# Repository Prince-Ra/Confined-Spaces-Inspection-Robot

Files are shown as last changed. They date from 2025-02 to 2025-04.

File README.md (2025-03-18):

# **Development of a Mobile Robot for Autonomous & Manual Inspection of Confined Spaces Using Multi-Sensor Detection Systems**  

This repository contains the code, simulations, and documentation for my final-year internship project. The project focuses on designing and developing an autonomous mobile robot equipped with a **multi-sensor detection system** for navigating and inspecting confined spaces. The system supports both **autonomous** and **manual navigation**, making it adaptable to various inspection scenarios.  

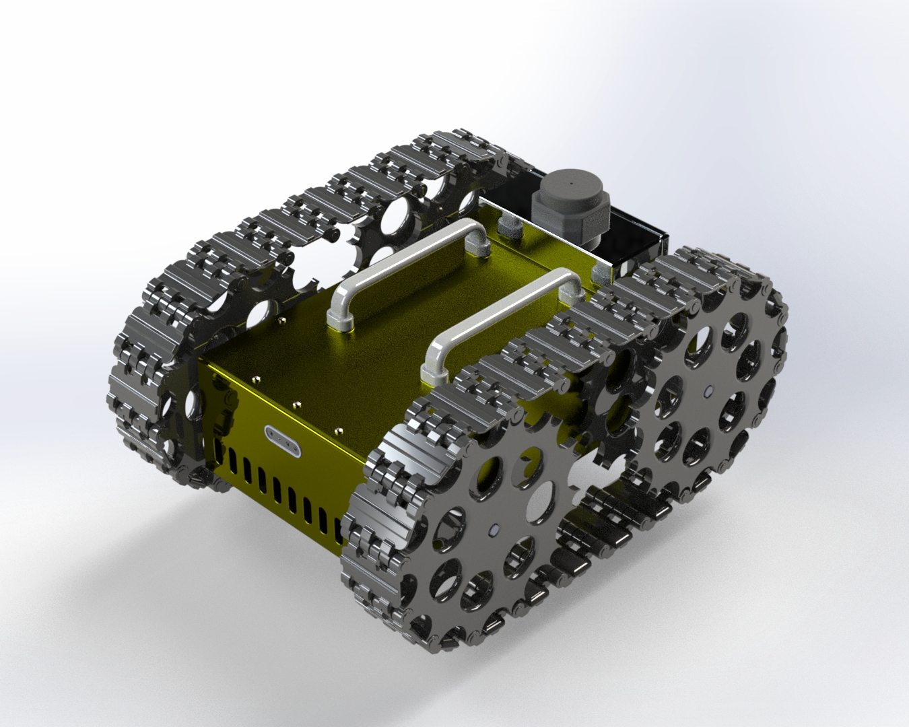
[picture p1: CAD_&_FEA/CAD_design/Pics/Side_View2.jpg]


## **Project Overview**  
🚀 **Autonomous & Manual Navigation**: Supports **autonomous path planning** and **manual control via RF remote interface**.  
🔍 **Multi-Sensor**: Integrated **LiDAR, stereo cameras, IMU, motor encoders, gas sensors, and temperature & humidity sensors** for comprehensive environmental monitoring.

🛠 **PCB Modular Sensor Hub**: Designed to adapt to multiple **sensors**.  
🎯 **Embedded Systems Development**: Developed firmware for **Jetson and STM32**.  
📊 **Structural & Thermal Analysis**: Conducted **FEA for vibration and load assessment** and **CFD for electronics cooling optimization** using **ANSYS**.  

## **Features**  
- **Autonomous Navigation**: ROS-based path planning and obstacle avoidance.  
- **Manual Navigation**: Remote control via a radiomaster.  
- **Multi-Sensor**:  
  - **LiDAR & Stereo Cameras** → Mapping & Obstacle Detection  
  - **IMU & Encoders** → Precise Localization  
  - **Gas, Temperature & Humidity Sensors** → Environmental Monitoring  
- **Gazebo-Based Simulation**: Virtual environment for testing and validation.  
- **ROS Integration**: Efficient robot control, mapping, and localization.  
- **PCB Modular Sensor Hub**: Compatible with different sensors for flexibility.  
- **Embedded Control**: Jetson for processing & STM32 for sensor acquisition and motor control.  
- **Structural & Thermal Optimization**: Vibration & Load Analysis ,Thermal Management for Electronics 

## **Contents**  
📂 **Code**: Navigation algorithms, sensor fusion logic, embedded firmware, and ROS nodes.  
📄 **Documentation**: System architecture, hardware design, sensor integration, and experimental results.  
🏗 **Simulations**: Gazebo environments for real-world scenario validation.  

## **Technologies Used**  
- **Programming Languages**: Python , C/C++  
- **Frameworks & Tools**: ROS2, OpenCV
- **Computer Aided design**: Solidworks
- **Simulation & Analysis**: Gazebo , ANSYS 
- **Hardware**: **LiDAR, stereo cameras, IMU, motor encoders, gas sensors, temperature & humidity sensors, Jetson, STM32**  

## **Contributing**  
Contributions are welcome! Feel free to submit issues, feature requests, or pull requests.  

## **Contact**  
For inquiries or collaboration, reach out via moataz.seghyar@usmba.ac.ma or connect on my linkedin page at Moataz Seghyar.

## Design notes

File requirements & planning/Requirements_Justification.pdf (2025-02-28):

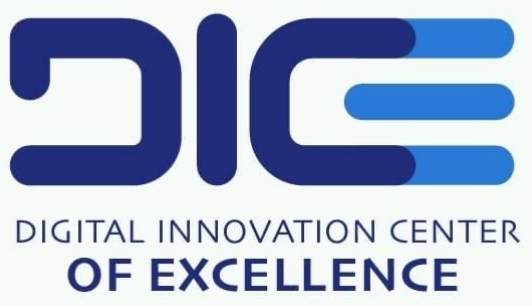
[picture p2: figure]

# Inspection Robot for Confined Spaces

## Requirements Justification

## Moataz SEGHYAR

### Document Purpose

This document is complementary to the specification document, providing detailed justifications for the selection of the various components used in the Inspection Robot for Confined Spaces. While the specification document outlines the technical requirements and design parameters, this document focuses on the analytical and engineering rationale behind the chosen components, ensuring that the design meets the operational requirements effectively and efficiently.

## Contents

1 Justification of Dimensions | 2
2 Justification of the Simplified Track System and Worm Drive Mechanism | 3
3 Fabrication Method Selection | 4
4 Material Selection Justification | 5
5 Motor Selection Justification | 8
6 Battery Selection Justification | 11
7 Power Consumption Analysis | 11

## Introduction

The proposed tracked robotic system is designed for navigation in confined and challenging environments, integrating Lidar, cameras, and multiple sensors for autonomous operation. Given its mission-critical requirements, the different parts have been carefully selected to balance mobility, stability, and payload capacity. This report provides a formal justification for maintaining these dimensions while optimizing weight, power consumption, and maneuverability.

## 1 Justification of Dimensions

The dimensions of 40x50x30 cm were chosen to ensure stability, traction, and maneuverability in confined and uneven environments. Key considerations include:

- Height (30 cm): Ensures operation within confined spaces (maximum height: 60 cm), providing clearance for sensors and mechanical extensions while maintaining flexibility.
- Low Center of Gravity: The 30 cm height reduces tipping risks on slopes, rough terrain, or obstacles, enhancing stability during dynamic movements.
- Footprint (40x50 cm): A larger contact surface improves traction by distributing weight evenly across the tracks, preventing sinking in soft or uneven surfaces.
- Track Proportion: A balanced 50 cm length and 40 cm width optimize weight distribution, maximizing grip while minimizing turning resistance for better maneuverability.
- Load Distribution: The wider frame reduces pressure on individual track sections, minimizing wear and improving obstacle handling, especially with modular 3D-printed tracks.

These dimensions balance stability, traction, and maneuverability, ensuring effective operation in confined spaces without compromising structural integrity or mobility.

## 2 Justification of the Simplified Track System and Worm Drive Mechanism

The choice of the propulsion system is a critical factor in ensuring the robot’s effectiveness in confined environments. Instead of a traditional tank-like track system with multiple road wheels, a simplified track system with two primary drive wheels was selected. Additionally, a worm drive mechanism was implemented to optimize torque transmission. The rationale behind these choices is outlined below.

### 2.1 Simplified Track System

The simplified track system, driven by two large wheels, offers several advantages over traditional tank-like mechanisms:

- Reduced Complexity and Friction: Eliminates multiple contact points, reducing mechanical complexity and friction losses for improved energy efficiency.
- Compatibility with Modular 3D-Printed Tracks: Ensures uniform track engagement and reduces mechanical stress on 3D-printed components, avoiding misalignment issues.
- Efficient Torque Transfer: Directs motor torque through two main drive wheels, ensuring effective power delivery.
- Enhanced Maneuverability: Reduces unnecessary contact points, enabling smoother turns and better adaptability in tight spaces.

### 2.2 Worm Drive Mechanism

The worm drive mechanism provides critical benefits for the robot’s operation:

- High Torque and Low-Speed Output: Offers significant gear reduction, increasing torque while reducing speed—ideal for controlled movement.
- Self-Locking Capability: Prevents back-driving, enhancing stability on inclined surfaces when motors are inactive.
- Compact and Robust Design: Simplifies the drivetrain by eliminating the need for multi-stage gear reductions, making it suitable for confined spaces.

## 3 Fabrication Method Selection

### 3.1 Sheet Metal Design for Chassis

The chassis is fabricated using sheet metal design due to its superior strength-to-weight ratio, cost-effectiveness, and ease of forming. This method is particularly well-suited for creating large, flat components like the chassis, ensuring precise and durable structures. Sheet metal fabrication allows for efficient production through processes such as metal cold forming and metal press forming, which are ideal for achieving the required structural integrity and lightweight design necessary for confined-space navigation. Compared to alternatives like casting or 3D printing, sheet metal offers better scalability and faster production for large parts.

### 3.2 3D Printing for Wheels and Tracks

For the wheels and tracks, 3D printing is employed to leverage its ability to produce complex geometries and lightweight structures. This method is particularly advantageous for creating intricate designs that require flexibility and durability, such as modular tracks and custom wheel shapes. Unlike traditional manufacturing, 3D printing allows for rapid prototyping and customization, making it ideal for small, complex components. The process also reduces material waste and enables the use of high-strength polymers or composites, which are essential for optimizing the performance of the wheels and tracks in confined environments.

## 4 Material Selection Justification

By selecting a simplified track system and incorporating a worm drive, the design ensures an optimal balance between mechanical efficiency, stability, and adaptability, making it well-suited for confined-space navigation.

### 4.1 Minimum Required Yield Strength Calculation

To ensure the base plate can support a 20 kg load over the 40 cm × 50 cm span with minimal deformation, we determine the minimum required yield strength (σy) based on bending stress. The maximum bending stress in a uniformly loaded rectangular plate can be approximated as:

σ =

M
S

(1)

where:

- M = αPL is the maximum bending moment,
- S =

bh²
6

is the section modulus of the plate,

- P = mg = (20×9.81) N is the total applied force,
- L = 0.50 m is the longest span of the plate,
- b = 0.40 m is the plate width,
- h = 0.005 m is the plate thickness.

Assuming a worst-case scenario with α = 0.125 (for a uniformly distributed load on a simply supported beam), the bending moment is:

M = 0.125×P×L | (2)

Substituting P = 196.2 N:

M = 0.125×196.2×0.50 = 12.26 Nm | (3)

Now, computing the section modulus:

S =

bh²
6

=

0.40×(0.005)

2
6

= 1.67×10⁻⁶ m
3
| (4)

Thus, the bending stress is:

σ =

12.26
1.67×10⁻⁶
= 73.5 MPa | (5)

### 4.2 Material Selection

To select a material that meets the required strength, we analyzed the CES selection graph, where the x-axis represents the Price × Density product. This metric helps balance weight reduction and cost effectiveness while ensuring structural integrity.
From the CES graph (Figure 1), the selected Aluminum 2024-T36 offers the following:
- A yield strength of approximately 300-500 MPa, which exceeds the required 73 MPa, ensuring a safety factor of 4-7.
- A relatively low Price × Density product compared to other high-strength alloys such as tungsten or rhodium, making it an economical yet strong choice.
- A high stiffness-weight ratio, which minimizes deflection and enhances stability, ensuring reliable performance in confined space environments.
- Excellent suitability for sheet metal forming, including metal cold forming and metal press forming, as indicated in the selection report. This makes it an ideal choice for applications requiring precise and durable sheet metal components.

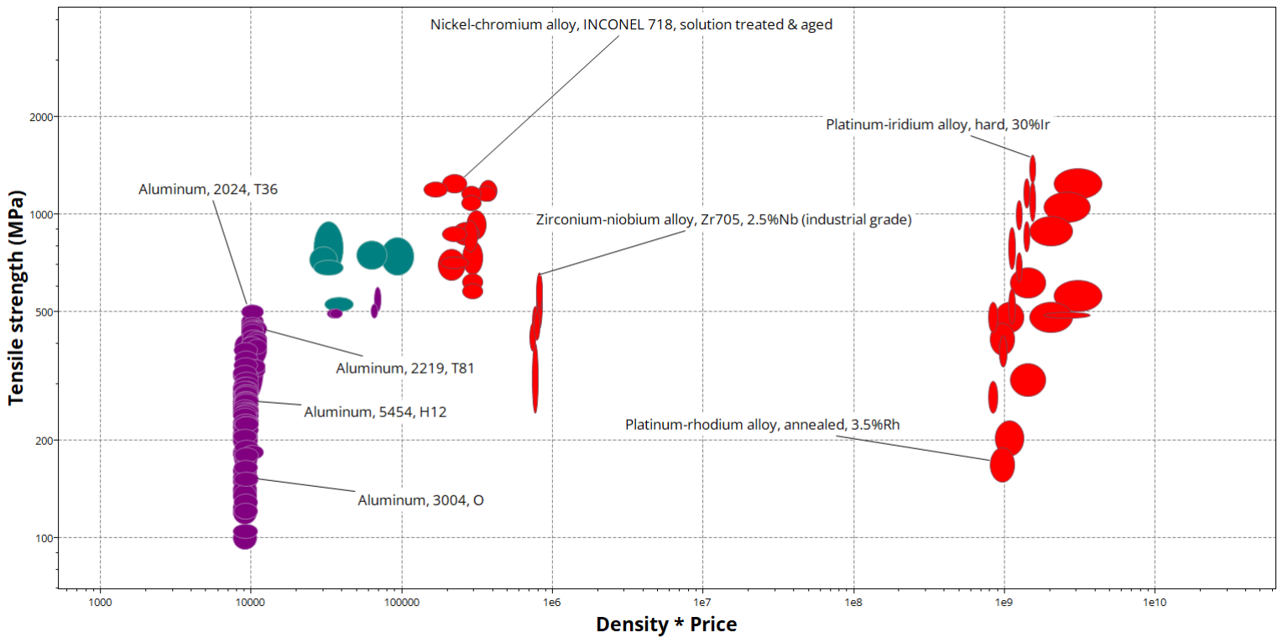
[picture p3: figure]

Figure 1: CES selection graph.

By selecting Aluminum 2024-T36, the robot achieves an optimal balance of stiffness, durability, and lightweight design, ensuring reliable operation in confined space environments. The significant safety margin provided by the material ensures robust performance even under unexpected loads or dynamic conditions.

### 4.3 Maximum Deformation Calculation

To calculate the maximum deformation of the plate, we use the formula for the deflection of a simply supported rectangular plate under a uniformly distributed load:

δ =

5qL⁴

384EI

(6)

where:

- q =

P
b×L =

196.2
0.40×0.50 = 981 N/m is the load per unit length,
- L = 0.50 m is the longest span of the plate,
- E = 73.1 GPa = 73.1×10⁹ Pa is the Young’s modulus of Aluminum 2024-T36,
- I =

bh³
12 =

0.40×(0.005)

3
12 = 4.17×10⁻⁹ m⁴
is the moment of inertia of the plate.

Substituting the values:

δ =

5×981×(0.50)

4
384×73.1×10⁹ ×4.17×10⁻⁹

(7)

δ =

5×981×0.0625
384×73.1×4.17

(8)

δ =

306.5625
117,073.92
≈ 0.00262 m = 2.62 mm | (9)

The maximum deformation of the plate is approximately 2.62 mm, which is within acceptable limits for most engineering applications, ensuring the plate remains stable and functional under the applied load.

## 5 Motor Selection Justification

To ensure the robot can operate effectively in confined spaces, we calculated the required torque and justified the selection of the 63ZYT04A-IP67 DC motor with a 1:100 worm gear reduction. The calculations include gravitational, acceleration, and frictional forces, as well as a safety factor to account for uncertainties.

### 5.1 Force Calculation

The total force required to move the robot includes the following components:

- Gravitational Force (Fg): The force required to overcome gravity on an incline.
- Acceleration Force (Fa): The force required to achieve the desired acceleration.
- Frictional Force (Ff): The force required to overcome static and kinetic friction.

The total force is given by:
Ftotal = Fg +Fa +Ff

### 5.2 Component Forces

1. Gravitational Force:
Fg = mgsin(θ)

where:

- m = 20kg (mass of the robot),
- g = 9.81m/s²
(acceleration due to gravity),
- θ = 45◦
(maximum incline angle for safety margin).

Substituting the values:
Fg = 20×9.81×sin(45◦
) = 138.7N
2. Acceleration Force:
Fa = ma

where:

- a = 0.5m/s²
(desired acceleration).

Substituting the values:
Fa = 20×0.5 = 10N
3. Frictional Force:
Ff = µmgcos(θ)

where:

- µ = 0.5 (coefficient of friction, static and kinetic).

Substituting the values:
Ff = 0.5×20×9.81×cos(45◦
) = 69.3N

### 5.3 Total Force with Safety Factor

The total force required is:

Ftotal = Fg +Fa +Ff = 138.7+10+69.3 = 218N

To account for uncertainties and dynamic loads, a safety factor of 1.5 is applied:

Ftotal, safety = 218×1.5 = 327N

### 5.4 Torque Calculation

The torque required at the wheels is:

T = Ftotal, safety ×r

where:

- r = 0.15m (wheel radius).

Substituting the values:
T = 327×0.15 = 49.05Nm

For two motors, the torque per motor is:

Tmotor =

49.05
2

= 24.53Nm per motor

### 5.5 Motor Justification

The selected 63ZYT04A-IP67 DC motor has the following specifications:

- Rated torque: 0.5Nm,
- Rated speed: 3000RPM,
- Gear reduction: 1 : 100.

The motor’s output torque after gear reduction is:

Tmotor, out = Tmotor ×Gear Ratio = 0.5×100 = 50Nm

The motor provides sufficient torque (50Nm > 24.53Nm) to meet the requirements, even with the safety factor.

### 5.6 Linear Speed Calculation

The linear speed of the robot is calculated as:

v = ω ×r

where:

- ω is the angular speed of the wheel in rad/s,
- r = 0.15m is the wheel radius.

The motor’s rated speed is 3000RPM. After a 1 : 100 gear reduction:

ωwheel =

3000
100

= 30RPM

Converting RPM to rad/s:

ωwheel = 30×

2π
60

= 3.14rad/s

The linear speed is:
v = 3.14×0.15 = 0.471m/s = 47.1cm/s

The 63ZYT04A-IP67 DC motor with a 1:100 worm gear reduction is well-suited for the robot, as it provides sufficient torque (50Nm) to meet the requirements (24.53Nm) and achieves a linear speed of 47.1 cm/s. The calculations include a safety factor of 1.5 to account for uncertainties and dynamic loads, ensuring reliable operation in confined spaces.

## 6 Battery Selection Justification

The selection of the battery is a critical decision that directly impacts the robot’s performance and operational duration. The chosen battery specifications are as follows:

- Voltage: 24V
- Capacity: 30Ah
- Total Energy: 720Wh

Rationale:

1. Voltage Compatibility: The 24V battery aligns with the voltage requirements of the DC motors and other high-power components, ensuring efficient power delivery without the need for additional voltage step-up mechanisms.
2. Energy Capacity: With a total energy capacity of 720Wh, the battery provides sufficient power to support the robot’s operations for the required duration.
3. Operational Duration: Based on the estimated total power consumption of 370W (320W for motors and 50W for electronics), the battery can support approximately 1.95 hours of continuous operation under full load. This meets our defined requirement of a 2-hour operating time, considering potential variations in load and usage patterns.

## 7 Power Consumption Analysis

The power consumption of the robot is divided into two main categories: the DC motors and the sensors and electronics. The total power consumption is designed to be 370W, with a safe margin included in the estimates. A detailed breakdown is provided below.

- DC Motors:

– Power: 160W each (320W total for two motors)

- Sensors and Electronics:

– Jetson Orin: 15W (for processing )

– Nucleo STM32 Development Board: 3W (for low-level control and interfacing)

– LiDAR (Slamtec RPLIDAR): 8W (for environment mapping and navigation)

– Stereo Camera (Intel Depth Camera D415): 8W (for depth perception and object detection)

– Temperature and Humidity Sensor (SHT31): 0.2W (for environmental monitoring)

– Gas Sensors (MQ-136 ZYMQ-135): 3W (for gas detection)

– Encoders: 1.5W (for tracking wheel rotation and speed)

– RF Receiver (RadioMaster ELRS): 1.5W (for wireless communication)

Total Sensors and Electronics: 50W

Calculations:

1. Total Energy Available:

Total Energy = Voltage×Capacity = 24V ×30Ah = 720W h

2. Total Power Consumption:

Total Power Consumption = Motor Power+Electronics Power = 320W +50W = 370W

3. Estimated Runtime:

Runtime =

Total Energy
Total Power Consumption

=

720W h
370W

≈ 1.95 hours

Considerations:

- Variable Load: The actual runtime may extend beyond 2 hours if the motors are not continuously operating at full load.
- Peak Power: The system is designed to handle peak power demands, such as during motor startups or direction changes, without compromising performance.

The power management system of the Inspection Robot for Confined Spaces is logically designed to meet the defined energy requirements. The selection of a 24V, 30Ah battery ensures that the robot can operate for at least 2 hours under full load, aligning with our operational goals. The calculations demonstrate that the system respects our requirements and provides a solid foundation for the robot’s successful deployment in confined spaces.

## Summary

In conclusion, the selected components—including the 63ZYT04A-IP67 motors, 24V 30Ah battery, and Aluminum 2024-T36 material—have been carefully justified based on their ability to meet the robot’s operational requirements in confined spaces. The proposed equipment ensures a balance of performance, durability, and cost-effectiveness, making it essential for the successful deployment of the inspection robot. We recommend proceeding with the purchase of these components to meet project timelines and objectives.

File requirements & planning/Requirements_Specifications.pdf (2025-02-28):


# Inspection Robot for Confined Spaces

## Requirements Specifications

## Moataz SEGHYAR

### Document Purpose

This document serves as the Project Requirements Specifications for the Inspection Robot for Confined Spaces. It outlines the technical requirements, design parameters, and functional specifications necessary to ensure the robot meets its operational objectives. While the complementary justification document provides detailed analytical and engineering rationale for component selection, this document focuses on defining the key performance criteria, operational constraints, and system requirements that guide the design and development process.

### Purpose

This project aims to develop an inspection robot for OCP, capable of operating in 60 cm high confined spaces within phosphate extraction machinery. The robot will:

- Detect toxic gases.
- Monitor temperature and humidity.
- Create a 3D map of the environment using LiDAR and depth cameras and navigate autonomously.

The robot addresses challenges such as limited accessibility, hazardous conditions, and the need for real-time data collection.

### Stakeholders

Key stakeholders include:

- OCP Engineers and Operators: Use the robot for machinery inspections.
- Safety Personnel: Ensure compliance with safety regulations.
- Maintenance Teams: Identify potential issues early.
- Project Managers: Oversee deployment and integration.

### Scope

The robot will:

- Operate in 60 cm high confined spaces with autonomous navigation and remote control options.
- Collect and transmit real-time data on gases, temperature, humidity, and 3D mapping.
- Withstand harsh industrial environments (e.g., dust, moisture, corrosive gases).
- Comply with IP65 safety standards.

### Project Overview

The inspection robot will:

- Use a tracked propulsion system for mobility.
- Navigate using LiDAR and a depth camera.
- Collect and transmit environmental data (temperature, humidity, gas concentrations).
- Operate in both manual remote control and autonomous modes.
- Feature a modular expansion port for additional components.
- Be designed to withstand harsh industrial environments (IP65-rated).

## System Architecture

The robot system consists of the following key components:

- Propulsion: Tracked system powered by two DC motors.
- Processing Unit: Jetson Nano for sensor data processing.
- Microcontroller: STM32 for motor and sensor control.
- Power System: 24V battery providing at least 1.5 hours of operation.
- Sensors: Industrial-grade sensors for temperature, humidity, and gas levels.
- Communication: Wireless connectivity for real-time data transmission and remote control.

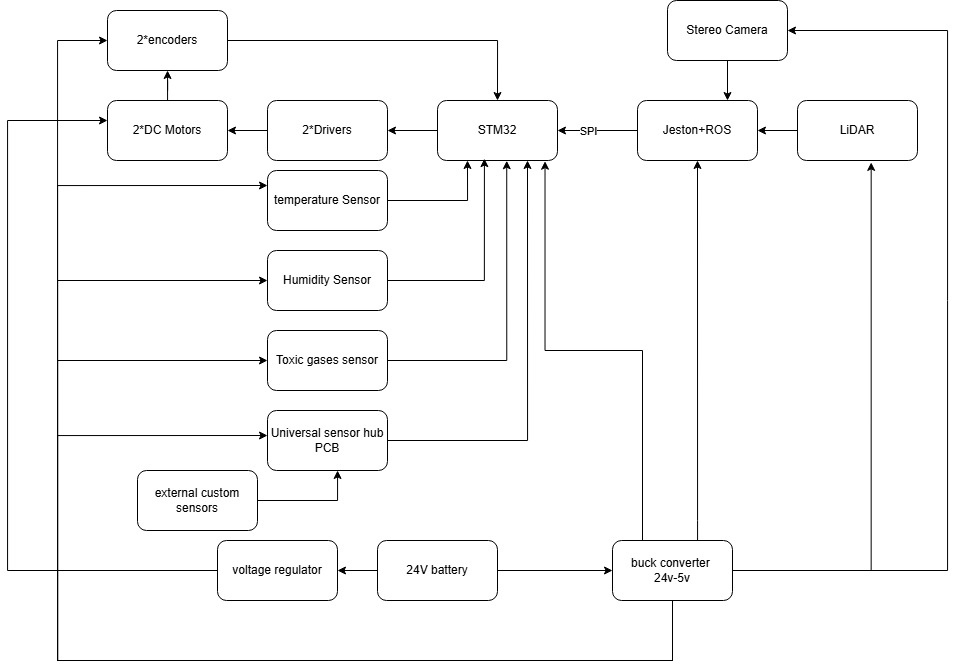
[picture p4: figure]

Figure 1: System Architecture

## Requirements

### Functional Requirements (FRs)

ID | Requirement
FR-01 | The robot shall use a tracked propulsion system powered by two DC motors.
FR-02 | The robot shall navigate autonomously using LiDAR and depth camera data.
FR-03 | The robot shall support manual remote control via a wireless interface.
FR-04 | The robot shall collect and transmit environmental sensor data.
FR-05 | The robot shall enable real-time data transmission.
FR-06 | The robot shall include a modular expansion bay for additional components.
FR-07 | The robot shall provide an emergency stop function for safety.

### Non-Functional Requirements (NFRs)

ID | Requirement
NFR-01 | The robot shall achieve a maximum speed of at least 20 cm/s.
NFR-02 | The robot shall operate continuously for a minimum of 2 hours on battery power.
NFR-03 | The robot shall be IP65-rated for dust and moisture resistance.
NFR-04 | The robot shall function in ambient temperatures between −20◦C and 50◦C.
NFR-05 | The robot’s communication latency shall not exceed 500 ms.
NFR-06 | The battery system shall support a minimum of 500 charge cycles.
NFR-07 | The modular expansion bay shall enable easy integration of additional sensors or tools.
NFR-08 | The robot shall weigh less than 20 kg for ease of transportation.

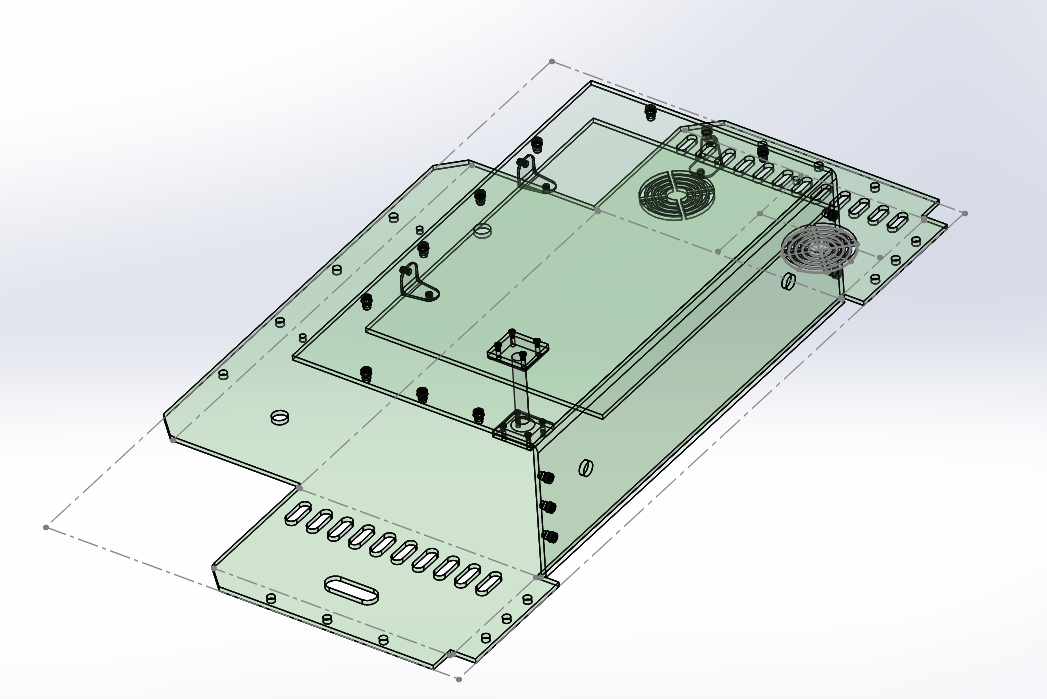
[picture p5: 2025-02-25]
CAD_&_FEA/CAD_design/Pics/Sheet_Metal_CAD.png

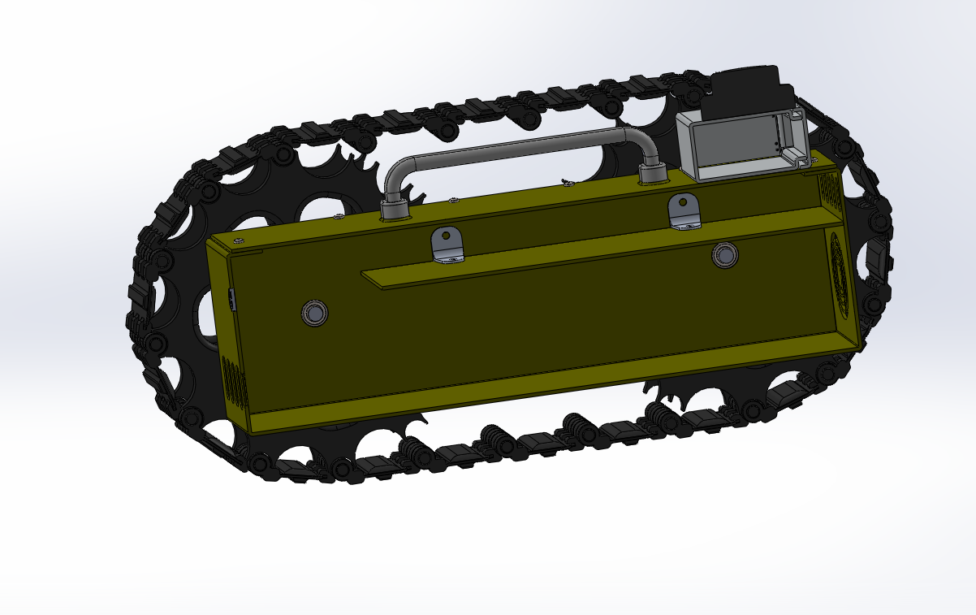
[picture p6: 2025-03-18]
CAD_&_FEA/CAD_design/Pics/Inside.png

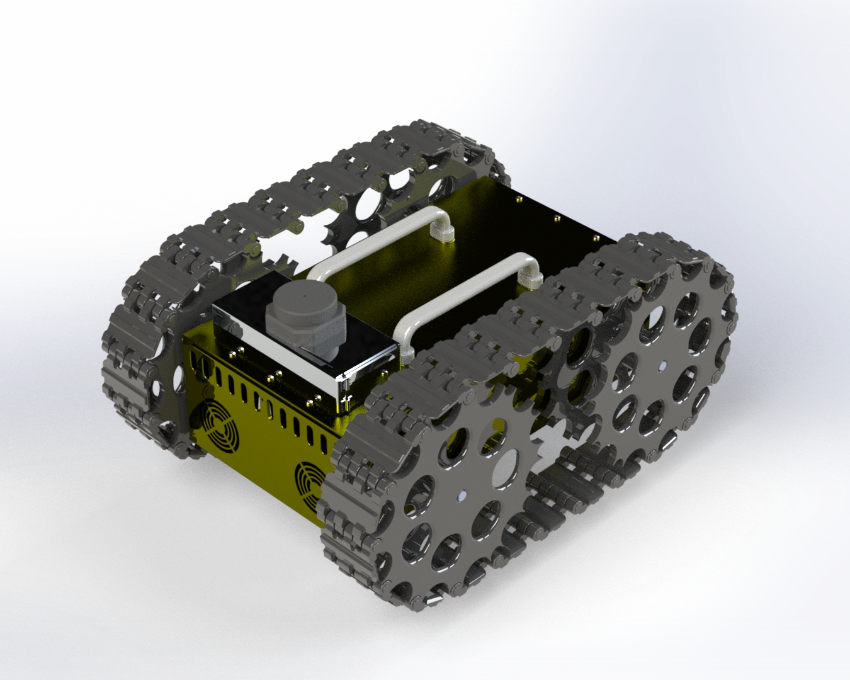
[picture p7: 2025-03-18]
CAD_&_FEA/CAD_design/Pics/Side_View1.jpg

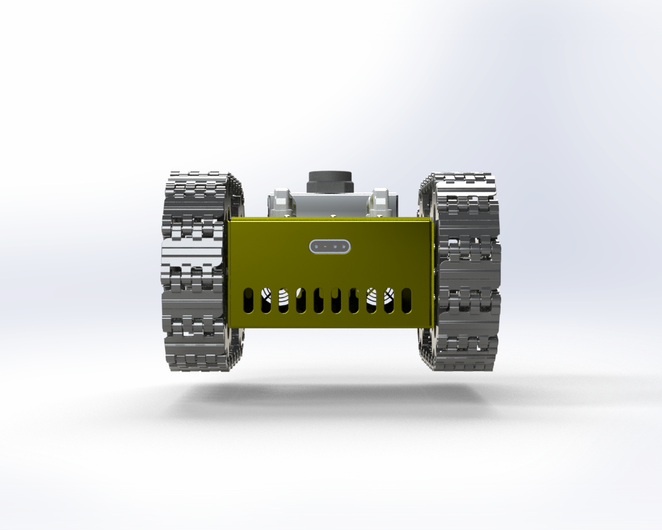
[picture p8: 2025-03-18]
CAD_&_FEA/CAD_design/Pics/Front_View.jpg

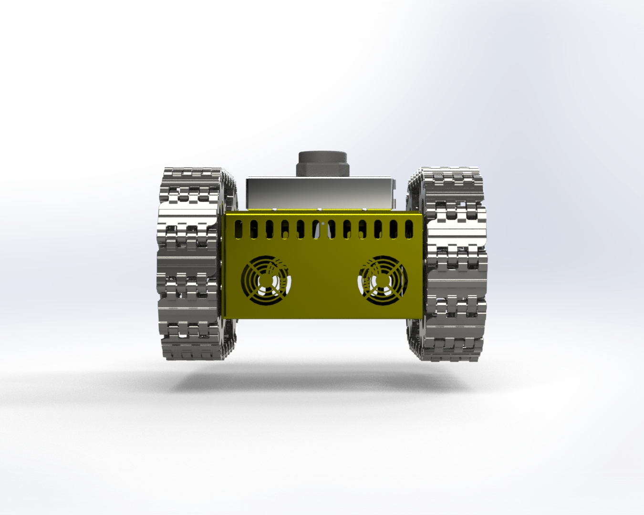
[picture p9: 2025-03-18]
CAD_&_FEA/CAD_design/Pics/Back_View.jpg

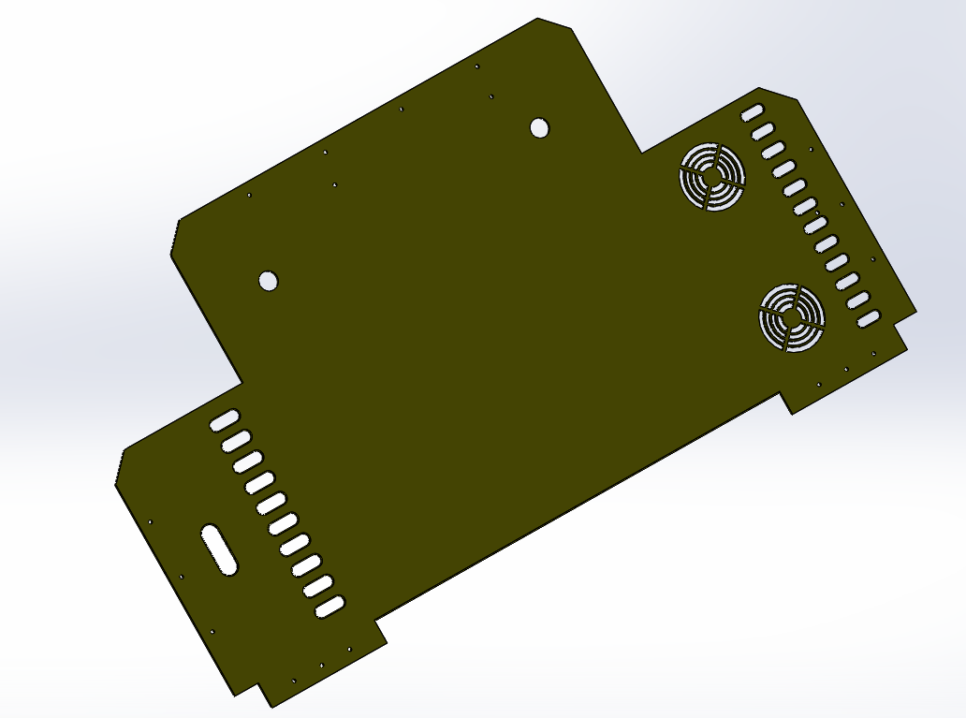
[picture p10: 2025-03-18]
CAD_&_FEA/CAD_design/Pics/Main_Body_Unfolded.png

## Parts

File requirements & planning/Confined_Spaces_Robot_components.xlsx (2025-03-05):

Component | Reference | Link
2*DC motors | D76(72)-24120-65 | https://wewinchina.en.made-in-china.com/product/jsOEMRQGlwVC/China-Diameter-76mm-24V-120-Watt-Micro-DC-Worm-Gear-Motor-with-Encoder.html
LiDAR | RPLiDAR S2L | https://www.dfrobot.com/product-2617.html
Motor Driver | Sabertooth dual 25A motor driver | https://www.dimensionengineering.com/products/sabertooth2x25
Deph Camera | Orbbec Gemini | https://www.electronics-lab.com/orbbec-gemini-335lg-3d-camera-offers-ip65-protection-and-long-range-depth-sensing-with-gmsl2-and-fakra-connectivity-for-roboti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
Gas Detector | S2652CO2 | https://www.ornicom.com/products/explosion-proof-gas-detectors/carbon-dioxide-gas-detector-explosion-proof-version-s2652co2.html
Temperature Sensor | Bikotronic | https://www.directindustry.com/prod/bikotronic/product-18848-1649076.html
IMU | olixSense™ IMU - X1 | https://olive-robotics.com/olixsense-imu-x1/
SBC | Jetson AGX Orin Industrial | https://www.nvidia.com/en-us/autonomous-machines/embedded-systems/jetson-orin/
Embedded board | STM32 Nucleo-144 | https://www.st.com/en/evaluation-tools/nucleo-h743zi.html#overview
RF sender | Horus X10S Express | https://www.frsky-rc.com/product/horus-x10s-express/
RF receiver | RX8R receiver | https://www.frsky-rc.com/product/rx8r-pro/
Battery | 30Ah capacity | https://fr.aliexpress.com/item/1005006843049096.html?utparam-url=scene%3Asearch%7Cquery_from%3A
Voltage regulator | DC-DC converter | https://www.vicorpower.com/high-density-high-efficiency-dc-dc-converters
24V-5V step down | MP2393 | https://www.monolithicpower.com/en/mp2393.html
Chargeur de batterie | 29.4V charger | https://fr.aliexpress.com/item/1005005761148433.html?utparam-url=scene%3Asearch%7Cquery_from%3A
4*Bearings | 6801ZZ | https://www.lebonroulement.com/tous-les-roulements-a-billes/71095-roulement-a-billes-6801-zz.html
Screws & Nuts | M4 pack | https://www.amazon.com/mxuteuk-Screws-Metric-Socket-Wrench%EF%BC%88285PCS%EF%BC%89/dp/B0CHJDMJ3H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
Material | Aluminum 6061 | https://www.xyt-al-industry.com/products/aluminum_plate_series/6000_series_1045173/6061_aluminum_plate.html
Service | company | Link
Sheet Metal forming | Menara | https://menara.industries/?lang=en

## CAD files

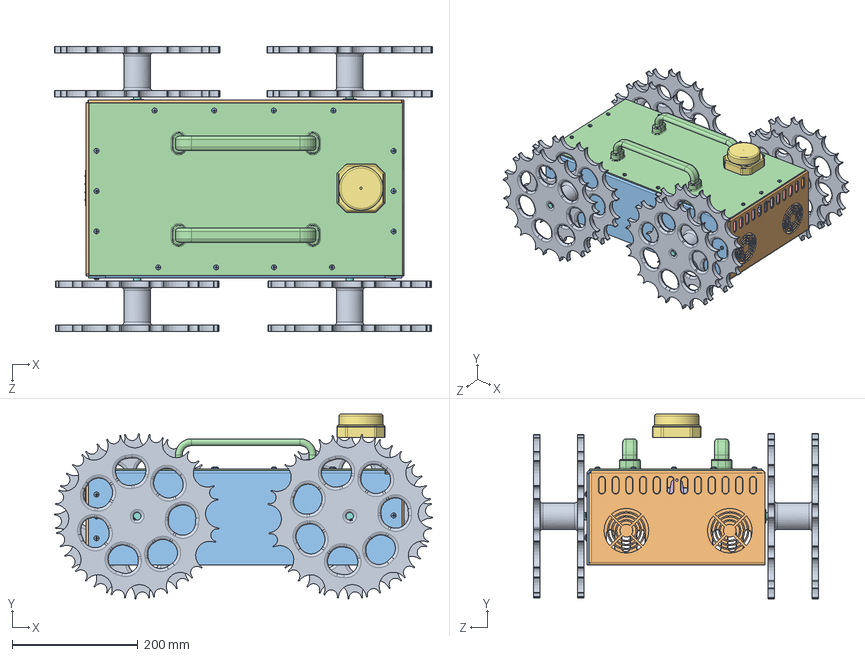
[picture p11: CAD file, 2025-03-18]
CAD_&_FEA/CAD_design/CAD_solidworks_files/AssemSheetMetal.SLDASM
601.2 x 294.0 x 453.0 mm
Copy of Copy of First Sheet Metal
Side Sheet Metal Assembly
Top Sheet Metal Assembly
mounting bracket x 3
Wheel x 4
LiDAR
Cil x 4
Part3^AssemSheetMetal
radial ball bearing_68_iso x 4
pan head cross recess screw_iso x 20

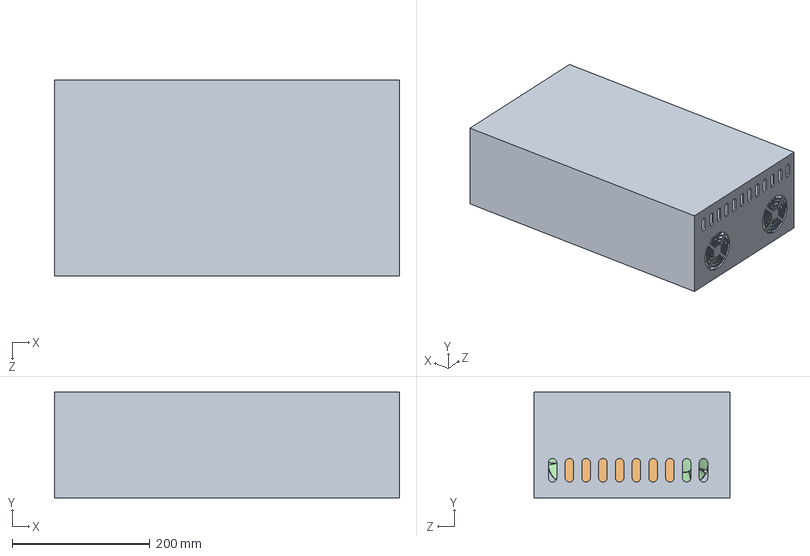
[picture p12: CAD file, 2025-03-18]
CAD_&_FEA/CAD_design/CAD_solidworks_files/Hallow_Fluent.SLDASM
501.7 x 154.0 x 284.7 mm
Fluent_Bodyddd
Part2^Hallow_Fluent
Part3^Hallow_Fluent
Fan x 2

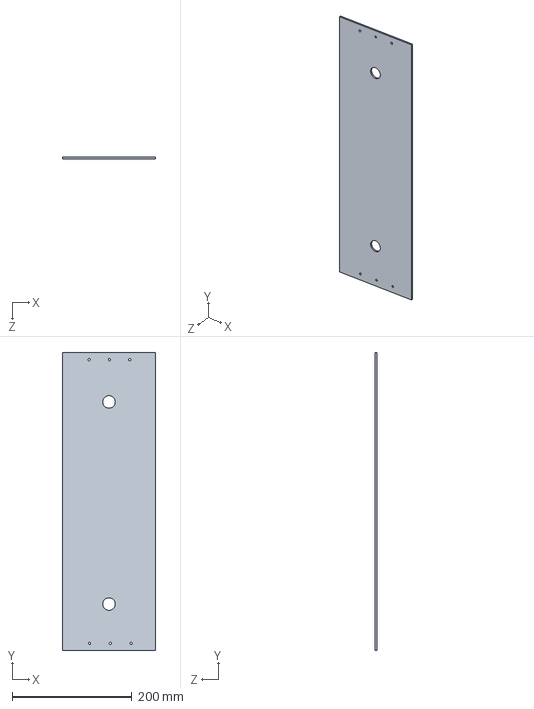
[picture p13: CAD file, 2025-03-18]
CAD_&_FEA/CAD_design/CAD_solidworks_files/Side Sheet Metal Assembly.SLDPRT
155.0 x 498.5 x 3.00 mm

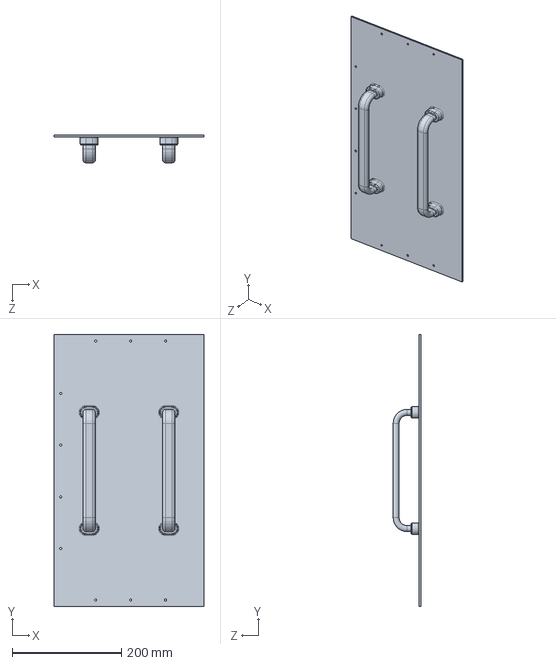
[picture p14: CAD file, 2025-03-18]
CAD_&_FEA/CAD_design/CAD_solidworks_files/Top Sheet Metal Assembly.SLDPRT
274.3 x 498.3 x 50.7 mm

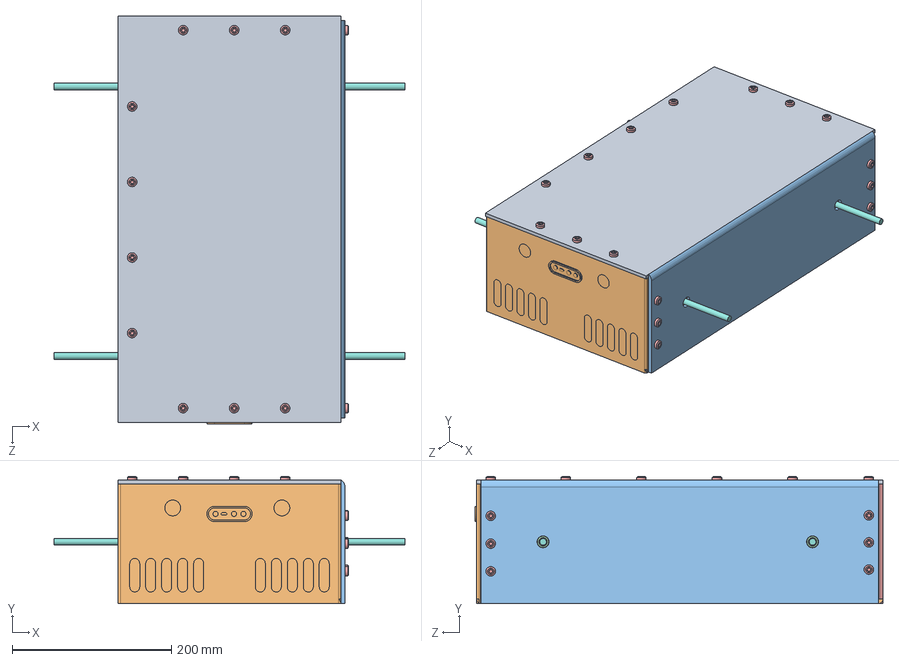
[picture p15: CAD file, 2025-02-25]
CAD_&_FEA/CAD_design/CAD_solidworks_files/Assembly.SLDASM
440.0 x 159.6 x 512.0 mm
angular contact ball bearing_68_iso x 4
Copy of Copy of First Sheet Metal
Side Sheet Metal Assembly
Top Sheet Metal Assembly
hexalobular socket pan head_iso x 16

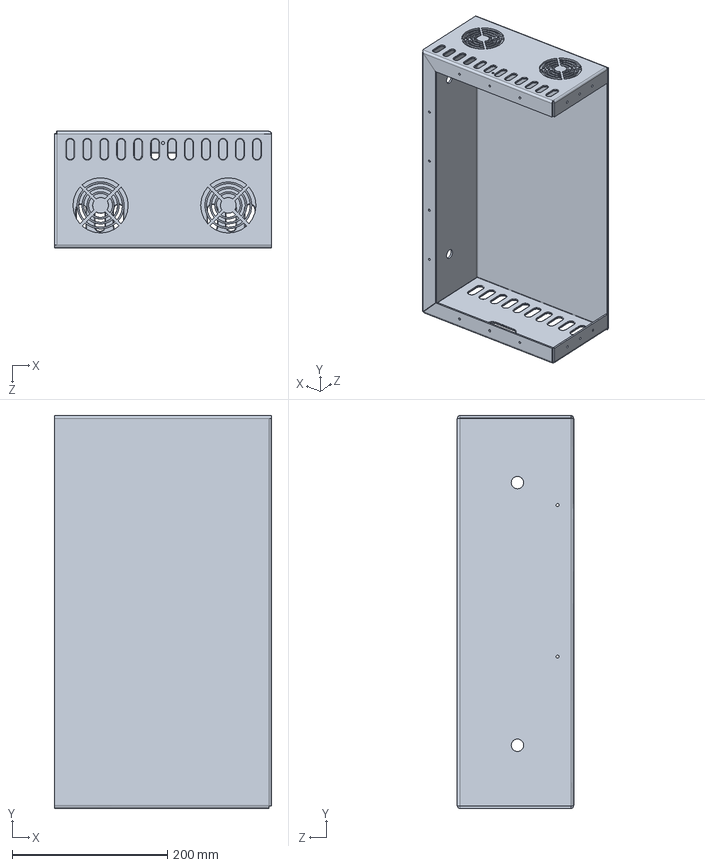
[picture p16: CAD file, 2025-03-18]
CAD_&_FEA/CAD_design/CAD_solidworks_files/Copy of Copy of First Sheet Metal.SLDPRT
280.0 x 506.0 x 150.0 mm

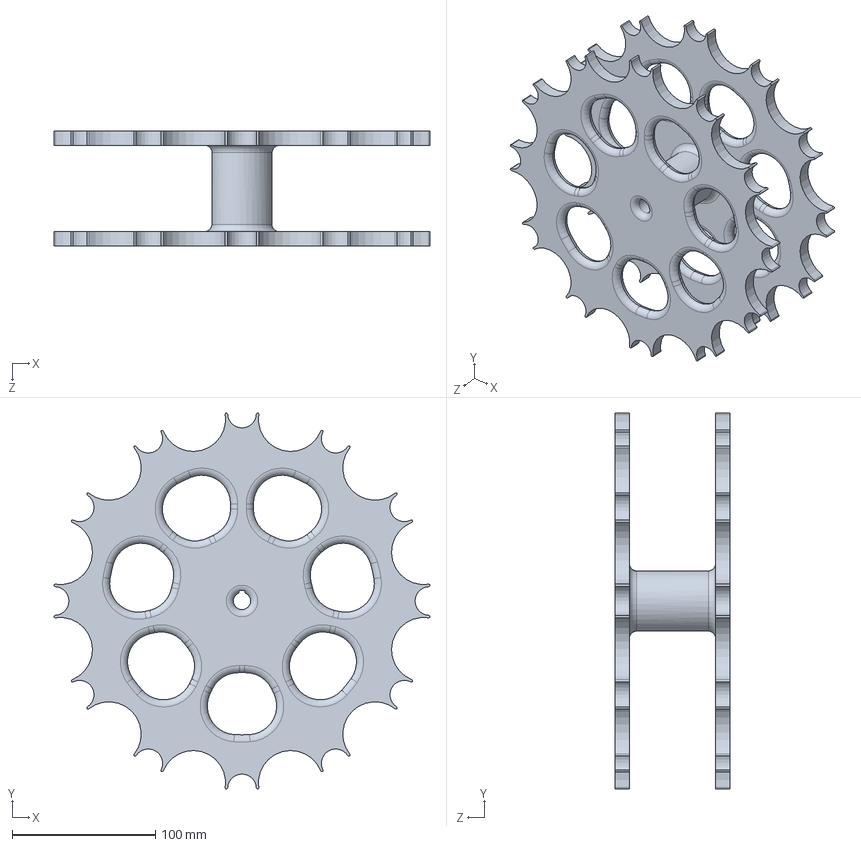
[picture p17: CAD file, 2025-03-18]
CAD_&_FEA/CAD_design/CAD_solidworks_files/Wheel.SLDPRT
262.2 x 262.2 x 80.0 mm

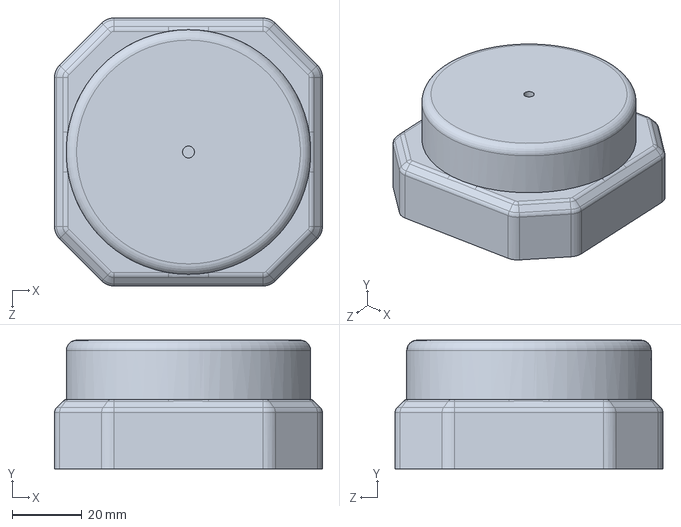
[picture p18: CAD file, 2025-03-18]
CAD_&_FEA/CAD_design/CAD_solidworks_files/LiDAR.SLDPRT
77.0 x 37.0 x 77.0 mm

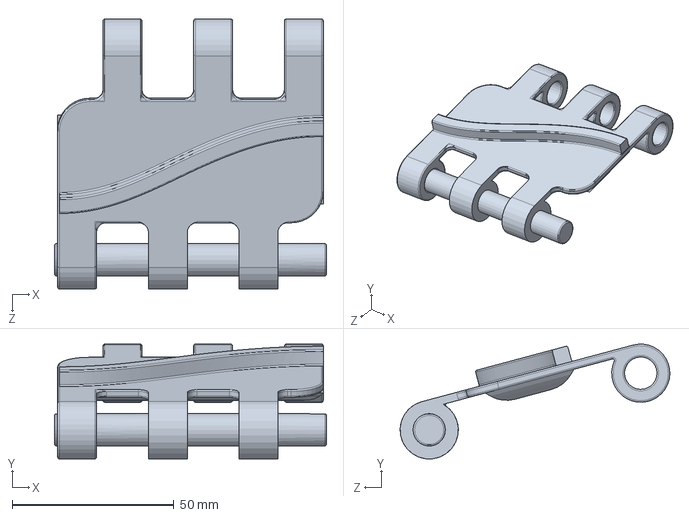
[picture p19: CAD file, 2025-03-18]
CAD_&_FEA/CAD_design/CAD_solidworks_files/Sketchforchain.SLDPRT
84.0 x 35.4 x 83.3 mm

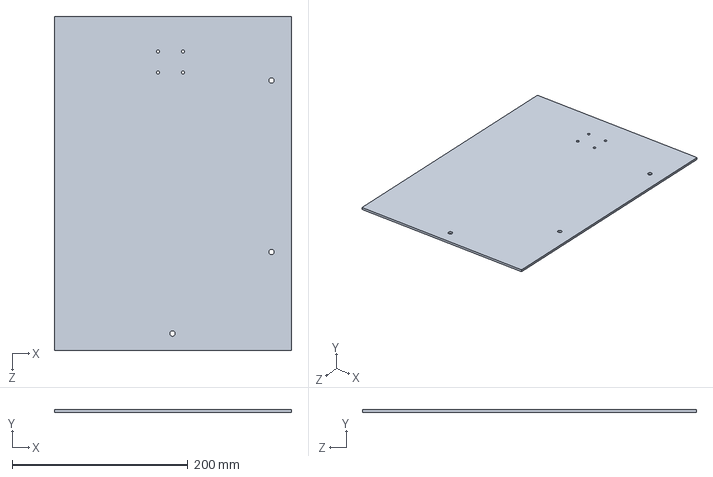
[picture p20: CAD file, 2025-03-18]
CAD_&_FEA/CAD_design/CAD_solidworks_files/Part3.SLDPRT
270.0 x 3.00 x 380.0 mm

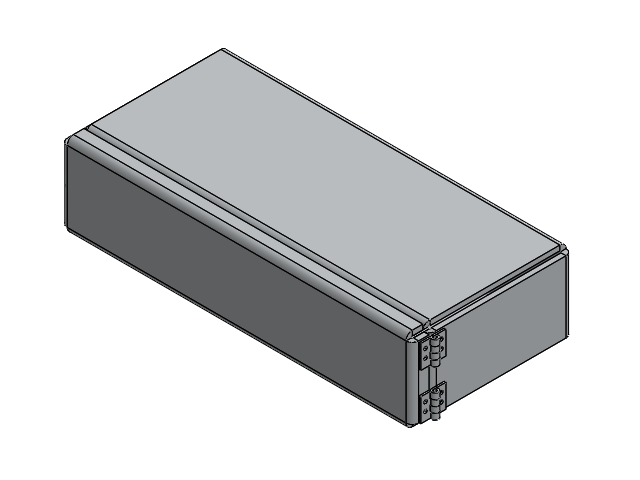
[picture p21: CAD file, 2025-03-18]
CAD_&_FEA/CAD_design/CAD_solidworks_files/electric_enclosureee.SLDASM
Electric_enclosure
Thingy_on_the_right x 2
Thingy_on_the_left x 2
Cover_thingy

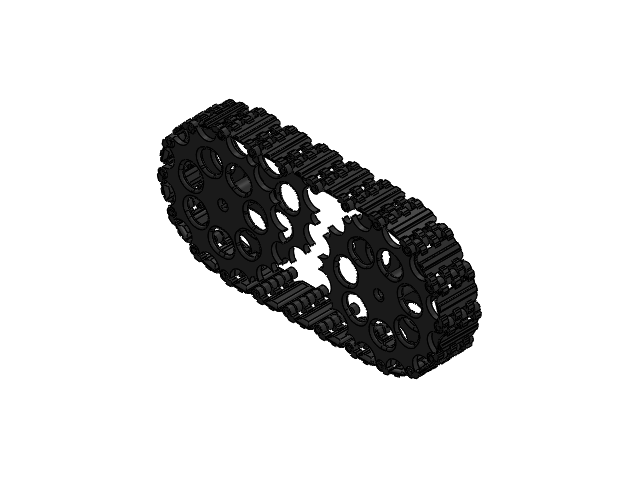
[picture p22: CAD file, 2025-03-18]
CAD_&_FEA/CAD_design/CAD_solidworks_files/Wheels_And_Chain.SLDASM
TheSketchssssss
Wheel x 2
Sketchforchain22 x 22

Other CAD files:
CAD_&_FEA/CAD_design/CAD_solidworks_files/Domain.SLDPRT
CAD_&_FEA/CAD_design/CAD_solidworks_files/mounting bracket.SLDPRT
CAD_&_FEA/CAD_design/CAD_solidworks_files/Cover_thingy.SLDPRT
CAD_&_FEA/CAD_design/CAD_solidworks_files/Thingy_on_the_right.SLDPRT
CAD_&_FEA/CAD_design/CAD_solidworks_files/TheSketchssssss.SLDPRT
CAD_&_FEA/CAD_design/CAD_solidworks_files/External_Sensor_Hub.SLDPRT
CAD_&_FEA/CAD_design/CAD_solidworks_files/Base Plane.SLDPRT
CAD_&_FEA/CAD_design/CAD_solidworks_files/Cil.SLDPRT
CAD_&_FEA/CAD_design/CAD_solidworks_files/Electric_enclosure.SLDPRT
CAD_&_FEA/CAD_design/CAD_solidworks_files/Fluent_Bodyddd.SLDPRT
CAD_&_FEA/CAD_design/CAD_solidworks_files/Front PlaneS.SLDPRT
CAD_&_FEA/CAD_design/CAD_solidworks_files/Part1.SLDPRT
CAD_&_FEA/CAD_design/CAD_solidworks_files/Part4.SLDPRT
CAD_&_FEA/CAD_design/CAD_solidworks_files/Part5.SLDPRT
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

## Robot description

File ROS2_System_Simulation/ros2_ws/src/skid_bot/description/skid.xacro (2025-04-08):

<?xml version="1.0"?>
<robot xmlns:xacro="http://www.ros.org/wiki/xacro" name="robot">

    <xacro:include filename="inertial_macros.xacro"/>

    <material name="white">
        <color rgba="1 1 1 1" />
    </material> 

    <material name="orange">
        <color rgba="1 0.3 0.1 1" />
    </material>

    <material name="blue">
        <color rgba="0.2 0.2 1 1" />
    </material>

    <material name="black">
        <color rgba="0 0 0 1" />
    </material>

    <material name="red">
        <color rgba="1 0 0 1" />
    </material>

    <!-- Example link -->
    <link name="base_link">
    </link>

    <joint name="base_footprint_joint" type="fixed">
        <parent link="base_link"/>
        <child link="base_footprint"/>
        <origin xyz="0 0 0" rpy="0 0 0"/>
    </joint>

    <link name="base_footprint">
    </link>

    <!-- CHASSIS LINK-->
    <joint name="chassis_joint" type="fixed">
        <parent link= "base_link"/>
        <child link="chassis"/>
        <origin xyz="0 0 0"/>
    </joint>

    <link name="chassis">
        <visual>
            <origin xyz="0 0 0.05"/>
            <geometry>
                <box size="0.5 0.3 0.2"/>
            </geometry>
            <material name="white"/>
        </visual>
        <collision>
            <geometry>
                <box size="0.5 0.3 0.2"/>
            </geometry>
        </collision>
        <xacro:inertial_box mass="0.5" x="1.0" y="0.6" z="0.3">
            <origin xyz="0 0 0.05" rpy="0 0 0"/>
        </xacro:inertial_box>  
    </link>

    <gazebo reference="chassis">
        <material>Gazebo/White</material>
    </gazebo>

    <!--FORWARD_LEFT LINK-->
    <joint name="fl_wheel_joint" type="continuous">
        <parent link="base_link"/>
        <child link="fl_wheel"/>
        <origin xyz="0.18 0.2 0" rpy="-${pi/2} 0 0"/>
        <axis xyz="0 0 1"/>
    </joint>

    <link name="fl_wheel">
        <visual>
            <geometry>
                <cylinder radius="0.15" length="0.1"/>
            </geometry>
            <material name="blue"/>
        </visual>
        <collision>
            <geometry>
                <cylinder radius="0.15" length="0.1"/>
            </geometry>
        </collision>
        <xacro:inertial_cylinder mass="0.1" length="0.1" radius="0.15">
            <origin xyz="0 0 0" rpy="0 0 0"/>
        </xacro:inertial_cylinder>
    </link>

    <gazebo reference="fl_wheel">
        <material>Gazebo/Blue</material>
    </gazebo>

    <!--FORWARD_RIGHT LINK-->
    <joint name="fr_wheel_joint" type="continuous">
        <parent link="base_link"/>
        <child link="fr_wheel"/>
        <origin xyz="0.18 -0.2 0" rpy="-${pi/2} 0 0"/>
        <axis xyz="0 0 1"/>
    </joint>

    <link name="fr_wheel">
        <visual>
            <geometry>
                <cylinder radius="0.15" length="0.1"/>
            </geometry>
            <material name="blue"/>
        </visual>
        <collision>
            <geometry>
                <cylinder radius="0.15" length="0.1"/>
            </geometry>
        </collision>
        <xacro:inertial_cylinder mass="0.1" length="0.1" radius="0.15">
            <origin xyz="0 0 0" rpy="0 0 0"/>
        </xacro:inertial_cylinder>
    </link>
    <gazebo reference="fr_wheel">
        <material>Gazebo/Blue</material>
    </gazebo>

    <!--BACK_LEFT LINK-->
    <joint name="bl_wheel_joint" type="continuous">
        <parent link="base_link"/>
        <child link="bl_wheel"/>
        <origin xyz="-0.18 0.2 0" rpy="-${pi/2} 0 0"/>
        <axis xyz="0 0 1"/>
    </joint>

    <link name="bl_wheel">
        <visual>
            <geometry>
                <cylinder radius="0.15" length="0.1"/>
            </geometry>
            <material name="blue"/>
        </visual>
        <collision>
            <geometry>
                <cylinder radius="0.15" length="0.1"/>
            </geometry>
        </collision>
        <xacro:inertial_cylinder mass="0.1" length="0.1" radius="0.15">
            <origin xyz="0 0 0" rpy="0 0 0"/>
        </xacro:inertial_cylinder>
    </link>
    <gazebo reference="bl_wheel">
        <material>Gazebo/Blue</material>
    </gazebo>

    <!--BACK_RIGHT LINK-->
    <joint name="br_wheel_joint" type="continuous">
        <parent link="base_link"/>
        <child link="br_wheel"/>
        <origin xyz="-0.18 -0.2 0" rpy="-${pi/2} 0 0"/>
        <axis xyz="0 0 1"/>
    </joint>

    <link name="br_wheel">
        <visual>
            <geometry>
                <cylinder radius="0.15" length="0.1"/>
            </geometry>
            <material name="blue"/>
        </visual>
        <collision>
            <geometry>
                <cylinder radius="0.15" length="0.1"/>
            </geometry>
        </collision>
        <xacro:inertial_cylinder mass="0.1" length="0.1" radius="0.15">
            <origin xyz="0 0 0" rpy="0 0 0"/>
        </xacro:inertial_cylinder>
    </link>
    <gazebo reference="br_wheel">
        <material>Gazebo/Blue</material>
    </gazebo>

</robot>

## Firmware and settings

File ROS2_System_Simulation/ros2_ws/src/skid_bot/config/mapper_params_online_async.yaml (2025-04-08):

slam_toolbox:
  ros__parameters:

    # Plugin params
    solver_plugin: solver_plugins::CeresSolver
    ceres_linear_solver: SPARSE_NORMAL_CHOLESKY
    ceres_preconditioner: SCHUR_JACOBI
    ceres_trust_strategy: LEVENBERG_MARQUARDT
    ceres_dogleg_type: TRADITIONAL_DOGLEG
    ceres_loss_function: None

    # ROS Parameters
    odom_frame: odom
    map_frame: map
    base_frame: base_footprint
    scan_topic: /scan
    use_map_saver: true
    mode: localization # or mapping

    # if you'd like to immediately start continuing a map at a given pose
    # or at the dock, but they are mutually exclusive, if pose is given
    # will use pose
    map_file_name: /home/moataz/ros2_ws/my_map_serial
    # map_start_pose: [0.0, 0.0, 0.0]
    map_start_at_dock: true

    debug_logging: false
    throttle_scans: 1
    transform_publish_period: 0.02 #if 0 never publishes odometry
    map_update_interval: 5.0
    resolution: 0.05
    min_laser_range: 0.0 #for rastering images
    max_laser_range: 20.0 #for rastering images
    minimum_time_interval: 0.5
    transform_timeout: 0.2
    tf_buffer_duration: 30.
    stack_size_to_use: 40000000 #// program needs a larger stack size to serialize large maps
    enable_interactive_mode: true

    # General Parameters
    use_scan_matching: true
    use_scan_barycenter: true
    minimum_travel_distance: 0.5
    minimum_travel_heading: 0.5
    scan_buffer_size: 10
    scan_buffer_maximum_scan_distance: 10.0
    link_match_minimum_response_fine: 0.1  
    link_scan_maximum_distance: 1.5
    loop_search_maximum_distance: 3.0
    do_loop_closing: true 
    loop_match_minimum_chain_size: 10           
    loop_match_maximum_variance_coarse: 3.0  
    loop_match_minimum_response_coarse: 0.35    
    loop_match_minimum_response_fine: 0.45

    # Correlation Parameters - Correlation Parameters
    correlation_search_space_dimension: 0.5
    correlation_search_space_resolution: 0.01
    correlation_search_space_smear_deviation: 0.1 

    # Correlation Parameters - Loop Closure Parameters
    loop_search_space_dimension: 8.0
    loop_search_space_resolution: 0.05
    loop_search_space_smear_deviation: 0.03

    # Scan Matcher Parameters
    distance_variance_penalty: 0.5      
    angle_variance_penalty: 1.0    

    fine_search_angle_offset: 0.00349     
    coarse_search_angle_offset: 0.349   
    coarse_angle_resolution: 0.0349        
    minimum_angle_penalty: 0.9
    minimum_distance_penalty: 0.5
    use_response_expansion: true
